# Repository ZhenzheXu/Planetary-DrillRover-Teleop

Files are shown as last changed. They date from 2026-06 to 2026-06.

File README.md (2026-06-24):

# Planetary-DrillRover-Teleop

An open-source, IPEx-inspired planetary rover analogue for sand-field mobility, drill-assisted soil interaction, multimodal teleoperation, and field-test data logging.

This repository supports the paper:

**OS-Rover: An Open-Source Planetary Rover for Resource Prospecting with Drill-Assisted Sampling and Multimodal Teleoperation**

The repository currently contains the STM32F407IGT6 firmware, Raspberry Pi software, SolidWorks mechanical source files, demonstration video, raw field-test logs, processed output plots, and paper figures used for the experimental analysis.

> This project is a terrestrial research prototype inspired by publicly available IPEx/RASSOR-style excavation rover concepts. It is not a flight-ready spacecraft and is not an official NASA project.

---

## 1. Project Overview

OS-Rover is a compact four-wheel skid-steer rover prototype developed as a reproducible terrestrial analogue platform for space robotics education, prototyping, sand-field testing, and human-in-the-loop control research.

The rover integrates:

* Four-wheel skid-steer mobility
* Large-diameter modular wheels with replaceable tread segments
* Drill-assisted soil loosening
* Rotating collection-disc mechanism
* Collection-module arm motion
* Arm-assisted recovery and pit-escape capability
* STM32F407IGT6-based real-time embedded control
* Raspberry Pi 5 high-level computing
* Vision-based gesture teleoperation
* Conventional radio control through FS-i6X / iA6B SBUS receiver
* Optional Bluetooth or terminal command interface
* Serial telemetry logging for field demonstrations

The prototype is intended for laboratory and sand-field experiments rather than vacuum, reduced-gravity, radiation, or flight environments.

---

## 2. Repository Structure

```text
Planetary-DrillRover-Teleop/
├── firmware/
│   └── stm32f407igt6_rover_controller/
│
├── software/
│   └── raspberry_pi/
│       ├── bluetooth_bridge/
│       ├── data_logger/
│       └── gesture_control/
│
├── mechanical/
│   └── solidworks_source/
│
├── data/
│   ├── raw_logs/
│   ├── processed_plots/
│   └── paper_figures/
│
├── media/
│   ├── os_rover_demo.mp4
│   └── os_rover_demo_thumbnail.png
│
└── README.md
```

---

## 3. Demonstration Video

The supplementary demonstration video is available below.

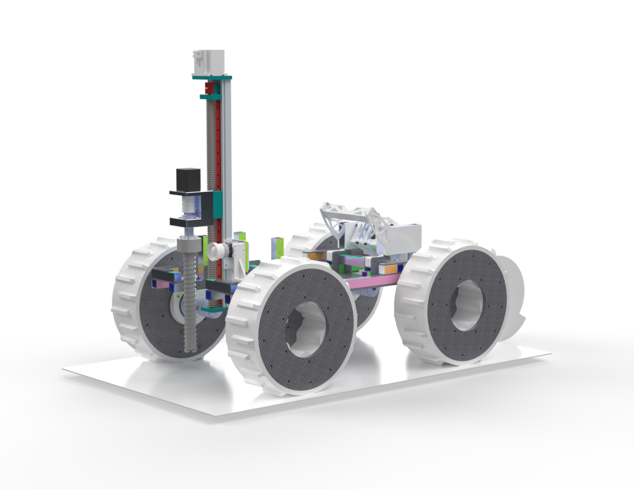
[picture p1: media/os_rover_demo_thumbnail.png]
OS-Rover demonstration video


The video presents 3D CAD model views, vision-based gesture control, collection-module arm motion, collection mechanism activation, four-wheel skid-steer mobility, drill-assisted soil interaction, pit-escape recovery, and telemetry feedback from the field tests.

---

## 4. Firmware

The STM32 firmware is located in:

```text
firmware/stm32f407igt6_rover_controller/
```

The firmware includes:

* Four-wheel chassis control
* CAN actuator control
* FS-i6X / iA6B SBUS receiver decoding
* Raspberry Pi serial command parsing
* Command arbitration between radio control and high-level commands
* Telemetry output for experiment logging

The project is configured for the STM32F407IGT6 controller and is organized as an STM32CubeMX / Keil MDK-ARM project.

---

## 5. Raspberry Pi Software

The Raspberry Pi software is located in:

```text
software/raspberry_pi/
```

The current software folders include:

* `gesture_control/`: vision-based gesture-control program
* `bluetooth_bridge/`: Bluetooth or terminal command bridge
* `data_logger/`: Python-based experiment logging scripts

The Raspberry Pi 5 is used for high-level command generation, gesture recognition, serial communication, and experiment data logging.

---

## 6. Mechanical Source Files

The mechanical source files are located in:

```text
mechanical/solidworks_source/
```

This folder contains the SolidWorks source files for the rover mechanical design, including the rover structure and functional modules.

The released mechanical files include source models related to:

* Rover chassis structure
* Wheel modules
* Drill mechanism
* Collection mechanism
* Collection-module arm structure

These files are provided as the current mechanical source release. Neutral CAD formats such as STEP files and printable STL files may be added in future updates.

---

## 7. Experimental Data and Result Plots

The experimental data are located in:

```text
data/
├── raw_logs/
├── processed_plots/
└── paper_figures/
```

* `raw_logs/` contains the original CSV telemetry logs recorded during field tests.
* `processed_plots/` contains output plots generated from the recorded log data.
* `paper_figures/` contains the final processed figures used in the paper.

The released data correspond to three field-test scenarios:

1. Flat-sand mobility and collection test
2. Slope-sand traversal test
3. Pit-escape recovery test

The logs include telemetry information such as wheel commands, control source, drill command, collection-disc command, collection-module arm state, and actuator feedback.

---

## 8. Example Result Figures

### Flat-Sand Test

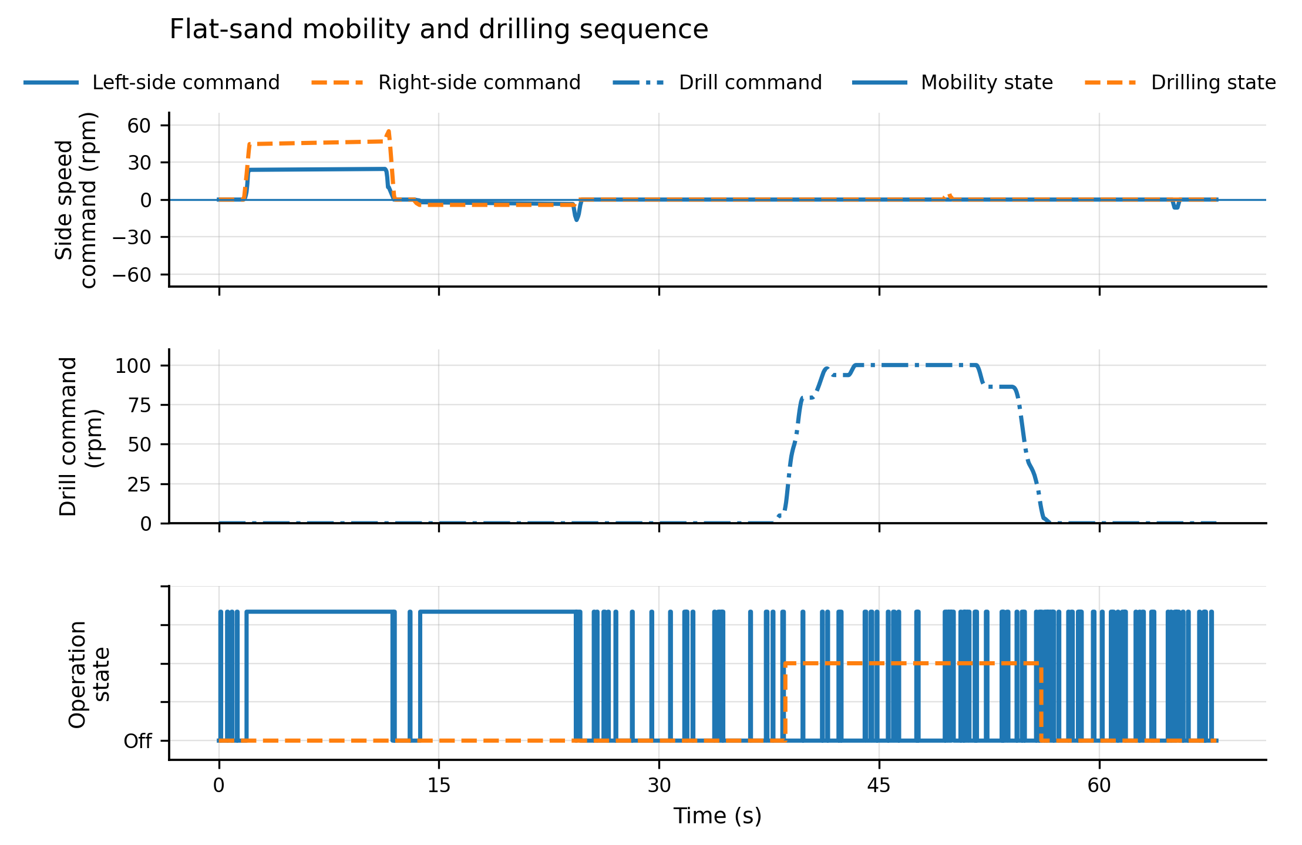
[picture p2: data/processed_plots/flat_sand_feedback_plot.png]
Flat-sand test result


### Slope-Traversal Test

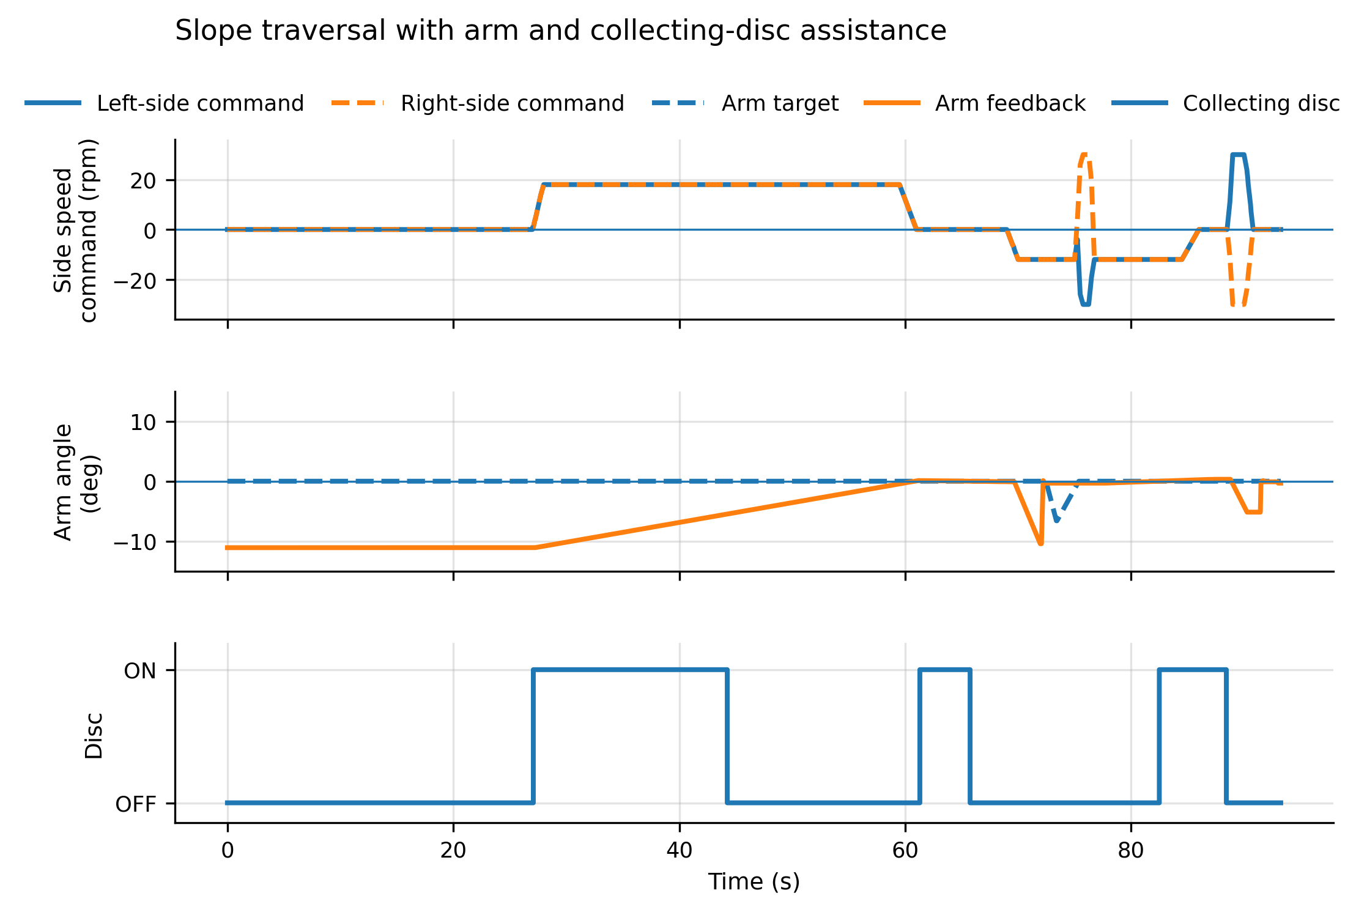
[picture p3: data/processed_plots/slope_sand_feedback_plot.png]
Slope-traversal test result


### Pit-Escape Test

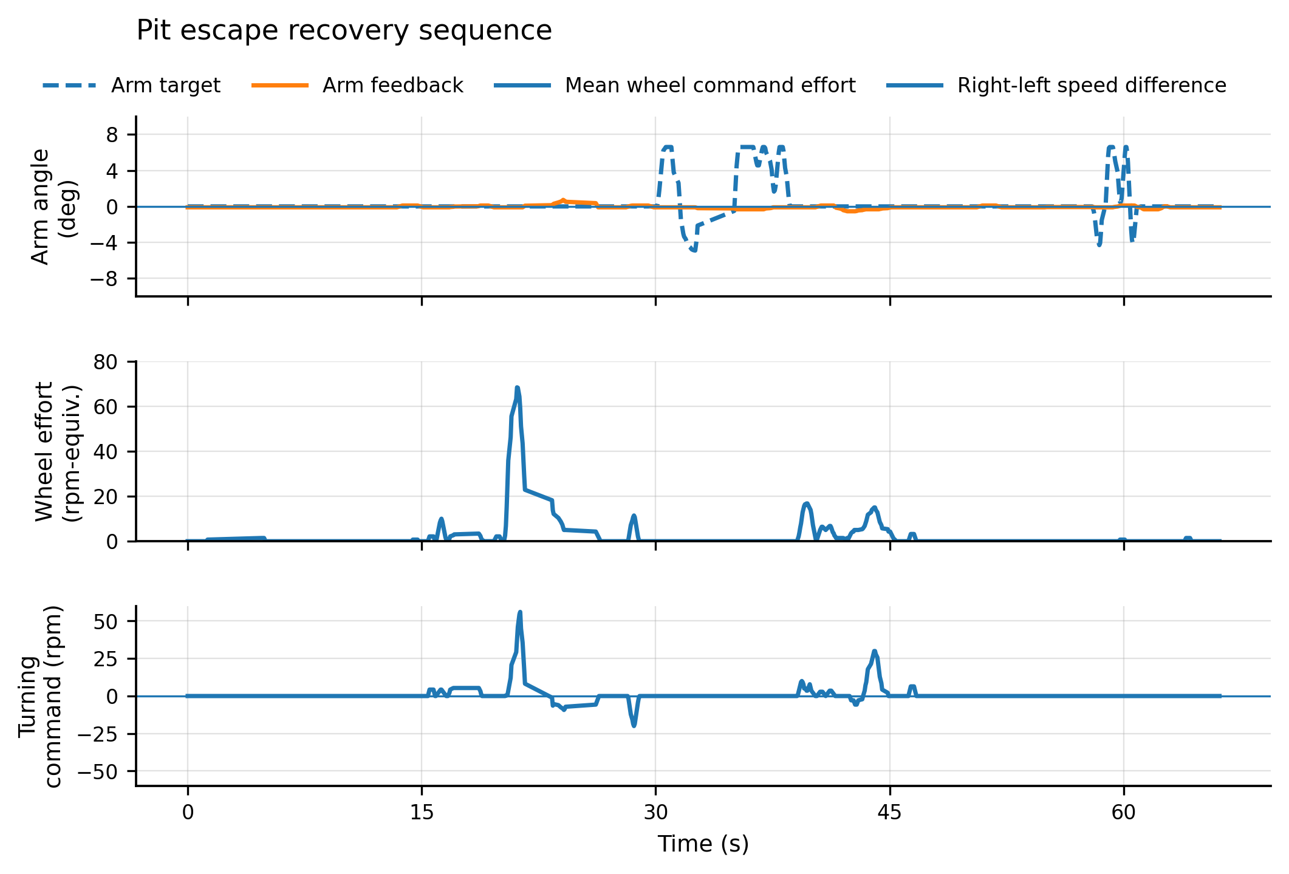
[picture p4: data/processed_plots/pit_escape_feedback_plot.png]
Pit-escape test result


### Paper Figure

Paper figure: three-scenario telemetry feedback

---

## 9. Field-Test Scenarios

### Flat-Sand Mobility and Collection Test

This scenario evaluates basic mobility, drill-assisted soil interaction, and collection-related actuation on flat sand.

### Slope-Sand Traversal Test

This scenario evaluates rover motion on inclined sandy terrain while recording the activity of the chassis and soil-working mechanisms.

### Pit-Escape Recovery Test

This scenario evaluates recovery behavior using coordinated chassis motion, drill actuation, collection-module arm motion, and collection mechanism activation.

---

## 10. Getting Started

### Clone the repository

```bash
git clone https://github.com/ZhenzheXu/Planetary-DrillRover-Teleop.git
cd Planetary-DrillRover-Teleop
```

### Open the STM32 firmware

Open the Keil project inside:

```text
firmware/stm32f407igt6_rover_controller/MDK-ARM/
```

or open the STM32CubeMX configuration file:

```text
firmware/stm32f407igt6_rover_controller/can.ioc
```

### Run Raspberry Pi scripts

Raspberry Pi scripts are organized under:

```text
software/raspberry_pi/
```

The gesture-control, Bluetooth bridge, and data-logging scripts are provided as the current high-level software release.

---

## 11. Current Release Status

This repository is under active development.

Current release contents:

* [x] STM32F407IGT6 rover-control firmware
* [x] Raspberry Pi software folders
* [x] SolidWorks mechanical source files
* [x] Demonstration video
* [x] Raw field-test logs
* [x] Processed output plots
* [x] Paper figures used for experimental analysis

Future updates may include additional wiring diagrams, neutral CAD exchange files, printable STL files, assembly notes, and extended operation documentation.

---

## 12. Citation

If you use this repository in academic work, please cite the related paper or this repository.

```bibtex
@misc{xu_planetary_drill_rover_2026,
  author       = {Xu, Zhenzhe},
  title        = {Planetary-DrillRover-Teleop: Open-source planetary drill rover teleoperation platform},
  year         = {2026},
  howpublished = {GitHub repository},
  url          = {https://github.com/ZhenzheXu/Planetary-DrillRover-Teleop}
}
```

---

## 13. License

A license file will be added before the final public release.

Recommended license structure:

* Firmware and software: MIT License or Apache-2.0
* Mechanical design files: CERN Open Hardware Licence or Creative Commons Attribution license

---

## 14. Safety Warning

This project is a research prototype intended for education, experimentation, and prototyping. It must be operated only by trained personnel in a controlled environment. Users are fully responsible for safe assembly, wiring, battery handling, and field operation. Do not operate the rover near people, unstable terrain, or hazardous conditions. The prototype is not intended for spaceflight, human-rated operation, or use in hazardous environments.

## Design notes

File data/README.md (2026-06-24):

# Experimental Data

This folder contains the experimental data and processed results used for the OS-Rover field demonstrations.

## Folder structure

- `raw_logs/` contains the original CSV telemetry logs recorded during the field tests.
- `processed_plots/` contains output plots generated from the recorded log data.
- `paper_figures/` contains the final processed figures used in the paper.

## Field-test scenarios

The released data correspond to three field-test scenarios:

1. Flat-sand mobility and collection test
2. Slope-sand traversal test
3. Pit-escape recovery test

The logs include telemetry information such as wheel commands, control source, drill command, collection-disc command, collection-module arm state, and actuator feedback. The processed plots summarize the task-level activity of the mobility system, drill module, arm mechanism, and collection mechanism during the experiments.

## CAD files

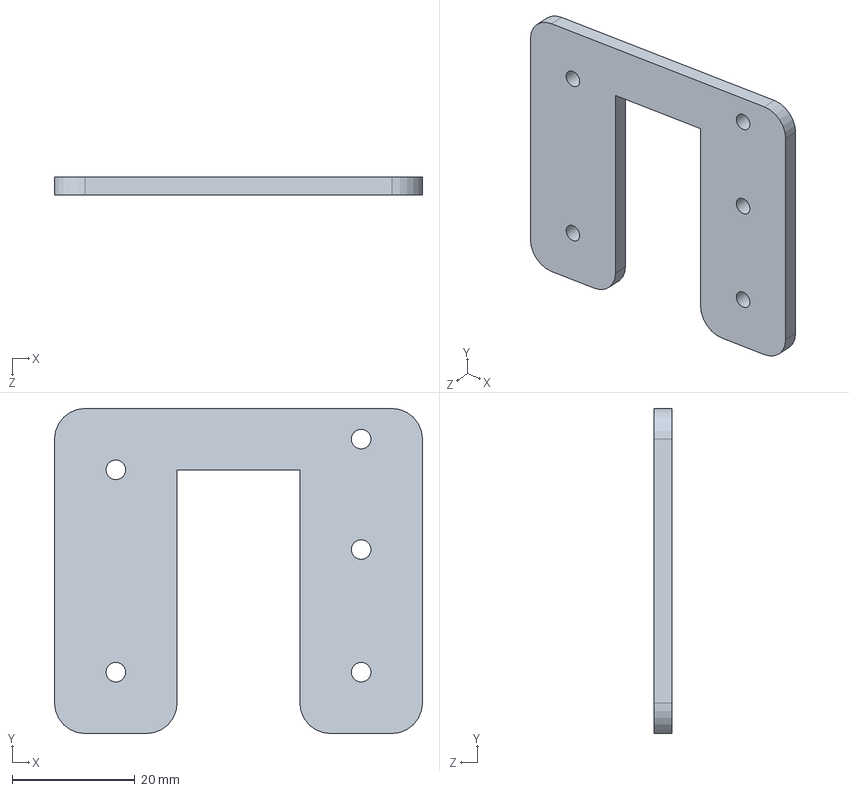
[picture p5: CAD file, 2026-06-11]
mechanical/solidworks_source/bucket_arm_vertical_column_reinforcement_plate.SLDPRT
60.0 x 53.0 x 3.00 mm

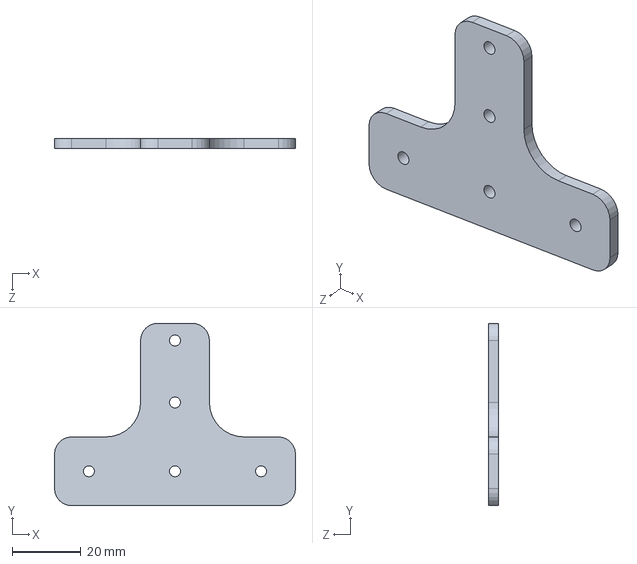
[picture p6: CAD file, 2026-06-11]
mechanical/solidworks_source/bucket_arm_vertical_aluminum_tube_2_mounting_plate.SLDPRT
70.0 x 53.0 x 3.00 mm

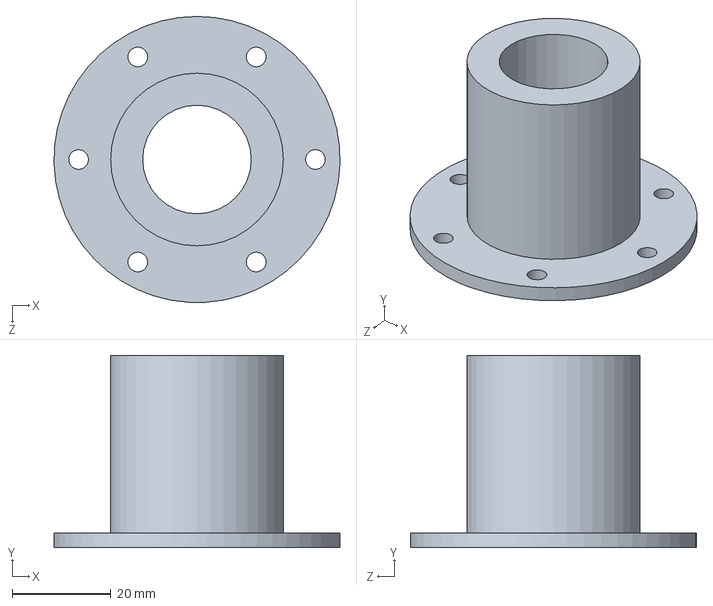
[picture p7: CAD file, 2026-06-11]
mechanical/solidworks_source/flange_plate.SLDPRT
58.0 x 39.0 x 58.0 mm

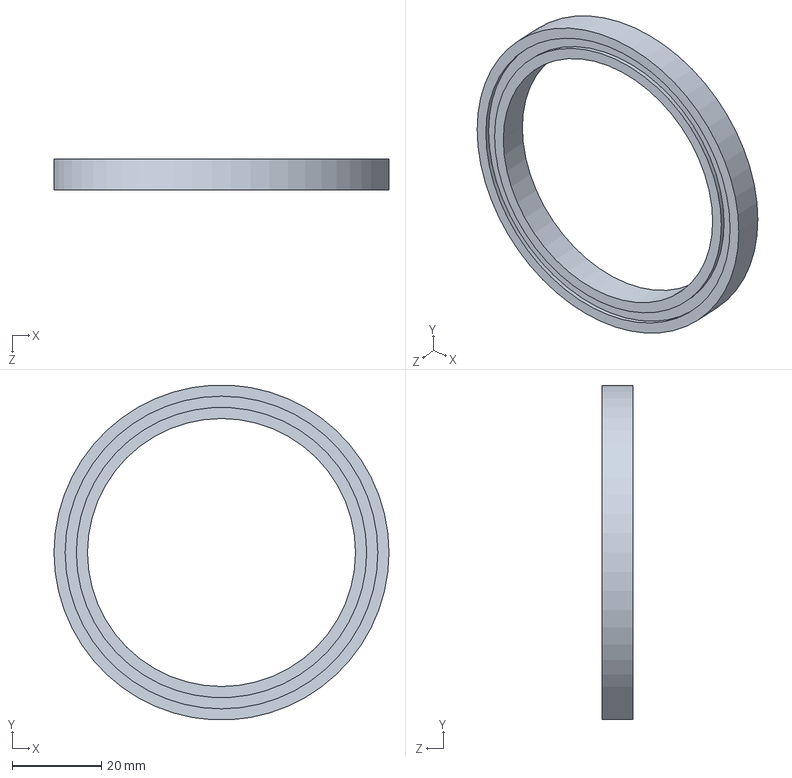
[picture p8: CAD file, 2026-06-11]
mechanical/solidworks_source/thin_section_deep_groove_ball_bearing_60x75x7.SLDPRT
75.0 x 74.9 x 7.00 mm

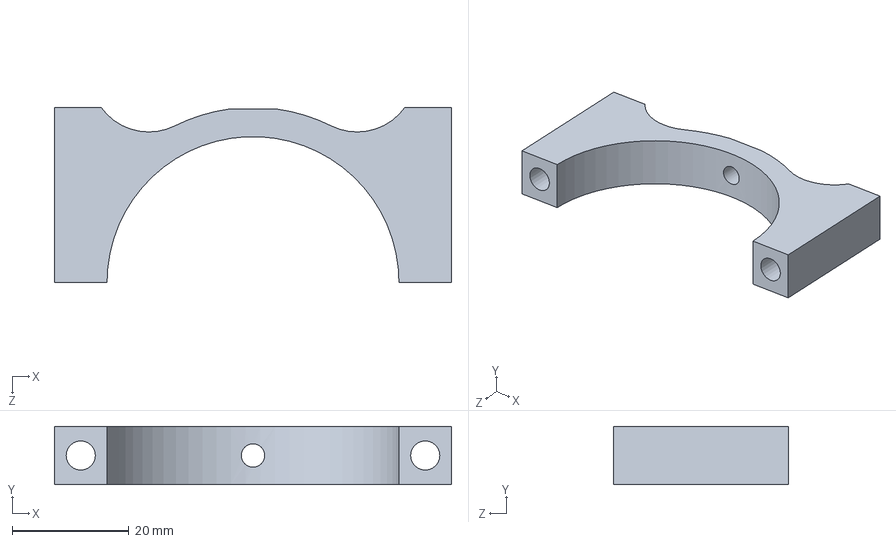
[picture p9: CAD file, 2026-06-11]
mechanical/solidworks_source/tube_clamp.SLDPRT
68.0 x 10.0 x 30.0 mm

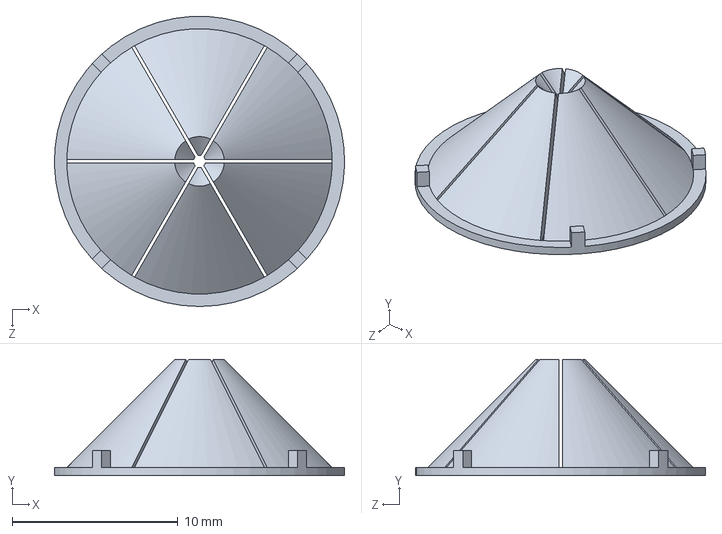
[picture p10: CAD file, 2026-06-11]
mechanical/solidworks_source/Sealing_Thin_Sheet.SLDPRT
17.5 x 7.01 x 17.5 mm

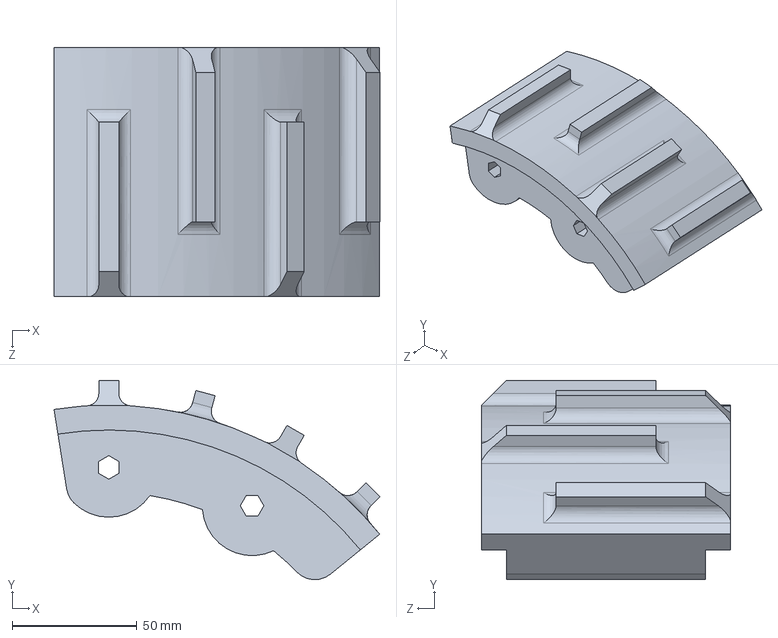
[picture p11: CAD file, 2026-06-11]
mechanical/solidworks_source/wheel_tread_staggered_rectangular_grouser_10mm_12x2_print_block.SLDPRT
130.9 x 80.0 x 100.0 mm

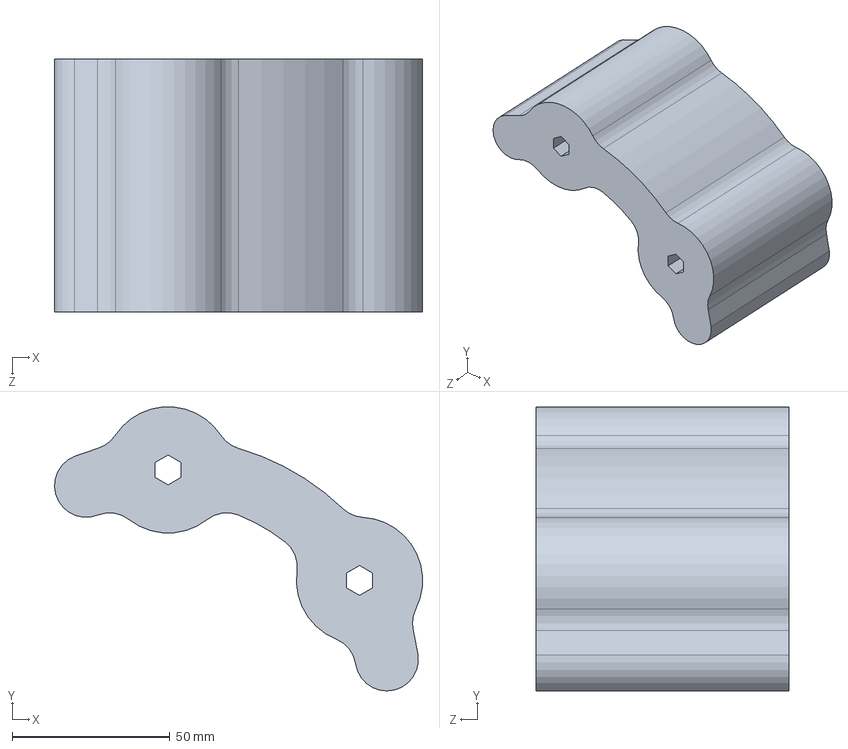
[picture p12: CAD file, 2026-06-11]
mechanical/solidworks_source/wheel_module_inner_spacer.SLDPRT
116.5 x 89.9 x 80.0 mm

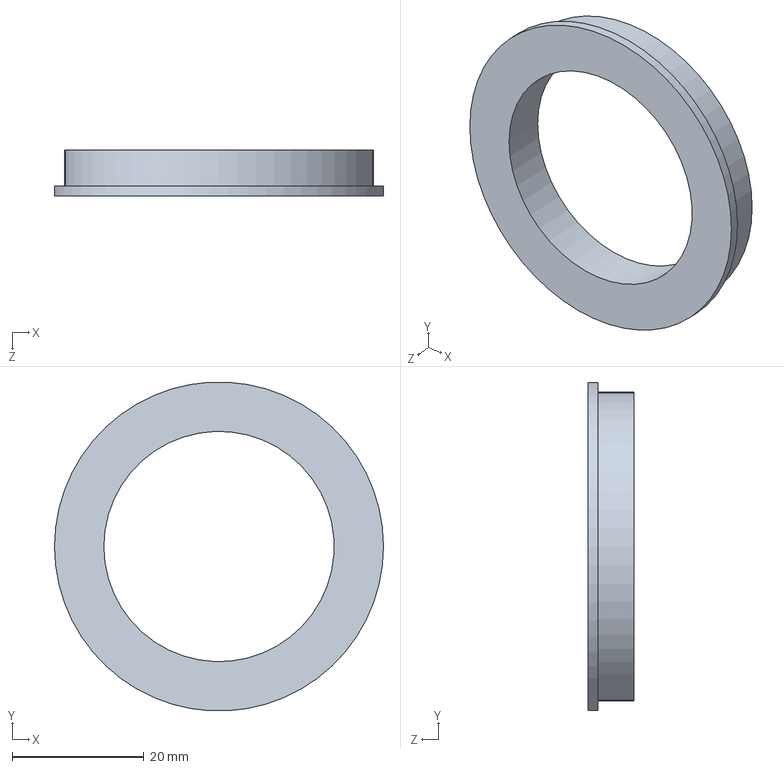
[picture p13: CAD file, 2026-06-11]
mechanical/solidworks_source/Flanged_Bearing_35-55-10.SLDPRT
50.0 x 49.9 x 7.00 mm

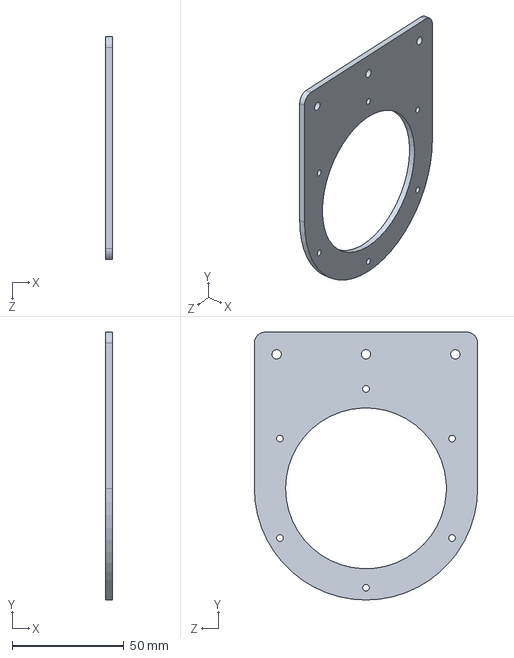
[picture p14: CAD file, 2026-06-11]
mechanical/solidworks_source/bearing_inner_clamping_plate_60x78.SLDPRT
3.00 x 120.0 x 100.0 mm

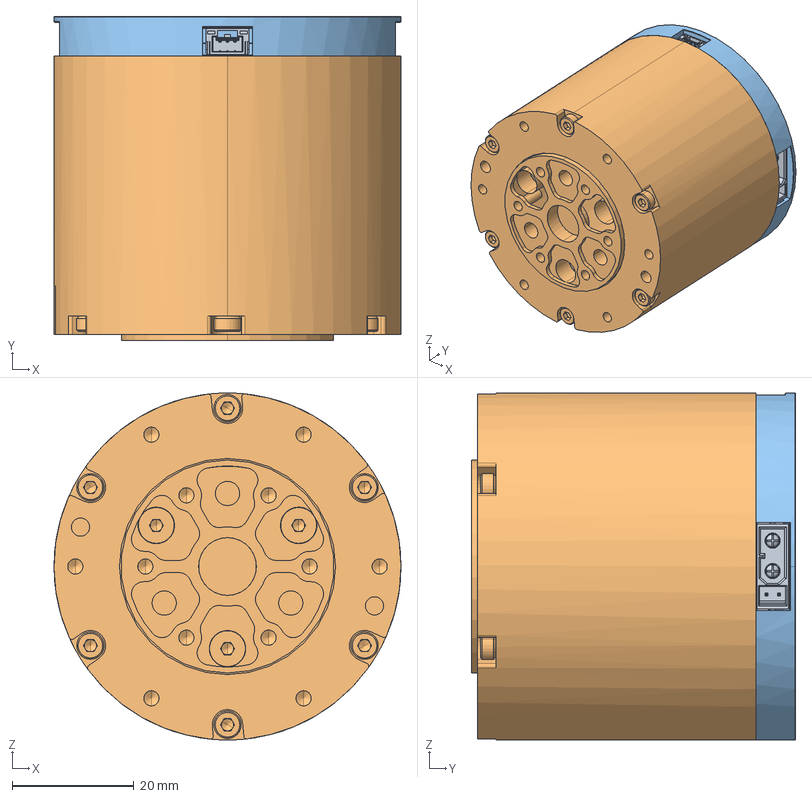
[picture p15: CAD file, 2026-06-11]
mechanical/solidworks_source/dm_4340__3d20240822_1(2)(1).stp
57.0 x 53.3 x 57.0 mm
DM_4340_3D_1_1_1_1_4
4310__VER_B0001_1_1_1_1_4
G43_V1_1_3-230824_4

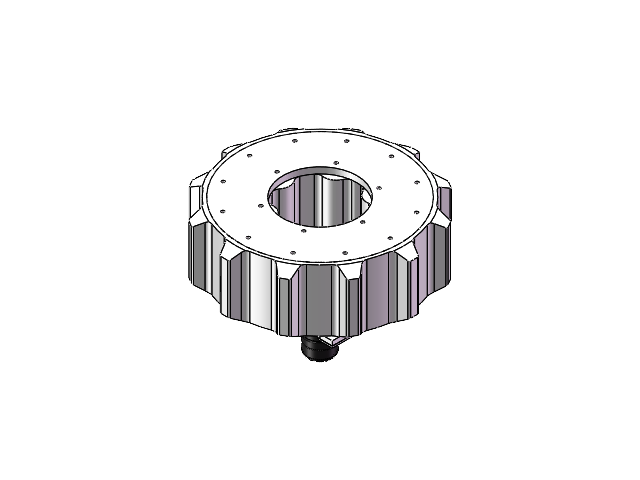
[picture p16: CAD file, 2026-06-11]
mechanical/solidworks_source/m3508_wheel_module.SLDASM
M3508直流无刷减速电机
3508法兰盘联轴器-hhr
淘宝-坚威旗舰店-杯头内六角螺丝M1,4M2M3M4M5M6 x 13
淘宝-坚威旗舰店-防松自紧螺母 x 6
铜柱5-80-hhr
3508法兰盘转接件-hhr
60-78-10薄壁深沟球轴承-hhr
3508安装板-hhr
60-78轴承内压板-hhr
60-78轴承垫块-hhr
60-78轴承外压板-hhr
60-78轴承外侧内圈压板-hhr
65-78轴承内侧外垫块-hhr
轮侧板-hhr
轮组内垫块-hhr x 3
轮组安装垫块-hhr
外轮板-hhr

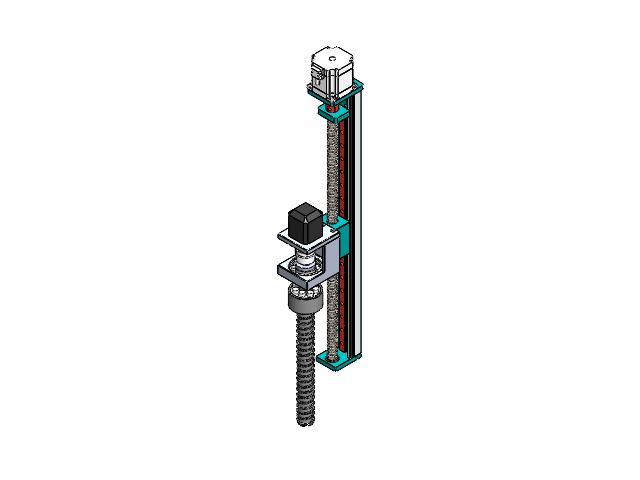
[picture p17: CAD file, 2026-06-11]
mechanical/solidworks_source/drilling_system_sample_assembly.SLDASM
传导轴
钻取平台
钻取平台连接板
42电机示意模型
联轴器示意模型
胀紧套ZJ2-18×47示意模型
螺纹钻管
防漏薄片
取芯钻头
______304mm.STEP
________.STEP
______.STEP
zhoucheng.STEP x 2
________-0.STEP
______-1.STEP
______-2.STEP
____.STEP
________-3.STEP
lianzhouqi.STEP
57______.STEP
57____.STEP

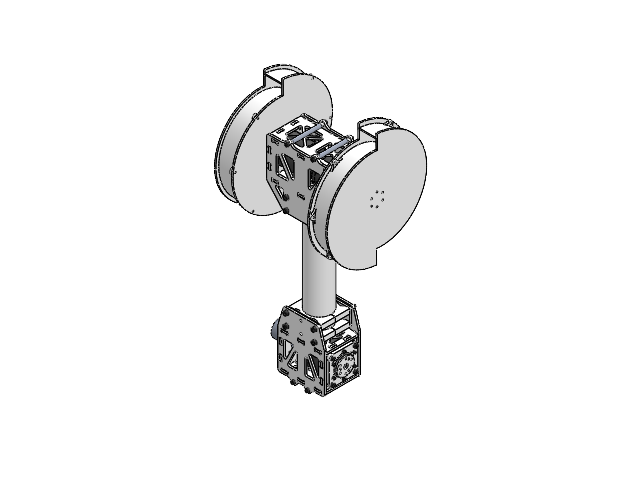
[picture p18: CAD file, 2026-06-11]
mechanical/solidworks_source/lever_arm_assembly.SLDASM
圆柱长臂
管夹 x 8
DM_4340_3D_1_1_1_1_4_1.stp x 3
4310__VER_B0001_1_1_1_1_4_1.stp x 3
G43_V1_1_3-230824_4_1.stp x 3
管夹固定板 x 4
t型连接板 x 2
t型连接支撑板 x 2
旋转轴 x 3
电机固定板 x 3
深沟球35-44-5 x 3
轴承固定 x 3
内六角圆柱头螺钉 M3x12 x 18
圆柱销 Φ4x25 x 6
内六角圆柱头螺钉 M4x15 x 4
内六角圆柱头螺钉 M4x12 x 14
内六角圆柱头螺钉 M3x22 x 12
内六角圆柱头螺钉 M5x85 x 8
内六角圆柱头螺钉 M4x16 x 4
轴系垫高打印件
螺旋挡板1
侧板2 x 2
固定板
法兰盘
固定垫片
t型连接板2 x 2
t型连接支撑板2 x 2
淘宝-坚威旗舰店-防松自紧螺母 x 2
60mm铝柱 x 4
尼龙套柱 x 8
螺旋挡板(左侧)

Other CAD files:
mechanical/solidworks_source/angular_contact_ball_bearing_7205c_gbt_292_2023.SLDASM
mechanical/solidworks_source/left_bucket_drum_assembly.SLDASM
mechanical/solidworks_source/bucket_drum_assembly.SLDASM
mechanical/solidworks_source/tube_clamp_assembly.SLDASM
mechanical/solidworks_source/Aluminum_Block_8_8_25.SLDPRT
mechanical/solidworks_source/Bucket_Arm_Stopper.SLDPRT
mechanical/solidworks_source/Bucket_Arm_Upright_Reinforcement_Clamp_Block.SLDPRT
mechanical/solidworks_source/Camera_Mounting_Bracket.SLDPRT
mechanical/solidworks_source/End_Cover_Spacer.SLDPRT
mechanical/solidworks_source/Flange_End_Cover.SLDPRT
mechanical/solidworks_source/Flanged_Bearing_Spacer_3D_Printed_Part.SLDPRT
mechanical/solidworks_source/Flanged_Bearing_Washer.SLDPRT
mechanical/solidworks_source/Long_Cylindrical_Arm.SLDPRT
mechanical/solidworks_source/MV-CU013-A0UMUC.SLDPRT
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

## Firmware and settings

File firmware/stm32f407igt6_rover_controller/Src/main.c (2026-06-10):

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

/* Includes ------------------------------------------------------------------*/
#include "main.h"
#include "can.h"
#include "dma.h"
#include "usart.h"
#include "gpio.h"

/* USER CODE BEGIN Includes */
#include "bsp_can.h"
#include "CAN_receive.h"
#include "i6x_receive.h"
#include "i6x.h"
#include <string.h>
#include <stdlib.h>
#include <stdio.h>
/* USER CODE END Includes */

/* USER CODE BEGIN PTD */

typedef struct
{
    float kp;
    float ki;
    float kd;

    float err;
    float last_err;
    float integral;

    float max_out;
    float max_integral;
} motor_pid_t;

typedef enum
{
    CONTROL_SOURCE_REMOTE = 0,
    CONTROL_SOURCE_VISION = 1
} control_source_t;

typedef struct
{
    uint8_t online;
    uint8_t err;
    uint8_t id;

    uint16_t pos_raw;
    uint16_t vel_raw;
    uint16_t torque_raw;

    float pos_rad;
    float vel_rad_s;
    float torque_nm;

    uint8_t t_mos;
    uint8_t t_rotor;

    uint32_t last_update_tick;
    uint32_t rx_count;
} dm4340_feedback_t;

/* USER CODE END PTD */

/* USER CODE BEGIN PD */

/* ========================= M3508 Chassis Definition ========================= */

#define LF_DIR   1
#define RF_DIR  -1
#define LR_DIR   1
#define RR_DIR  -1

#define RC_FORWARD_CH       1
#define RC_TURN_CH          0

#define RC_FORWARD_SIGN     1.0f
#define RC_TURN_SIGN        1.0f

#define RC_CH_MAX_VALUE     660.0f
#define RC_DEADBAND         35

#define MAX_FORWARD_RPM     220.0f
#define MAX_TURN_RPM        180.0f

#define PID_MAX_OUT         10000.0f
#define PID_MAX_INTEGRAL    30000.0f

#define CHASSIS_CONTROL_PERIOD_MS   2U

/* ========================= Raspberry Pi Vision UART Definition ========================= */

#define VISION_DEFAULT_SPEED_RPM       120.0f
#define VISION_DEFAULT_TURN_RPM        120.0f

#define VISION_UART_LINE_MAX_LEN       64U

/*
 * Telemetry output uses a second UART to avoid conflict with Raspberry Pi
 * gesture-control serial port.
 * Keep USART1 for gesture commands. Use USART6 TX -> second USB-TTL RX for feedback.
 * If your CubeMX enables another UART such as USART2, change huart6 to huart2.
 */
#define TELEMETRY_UART_HANDLE          huart6

/*
 * Arbitration rule required by user:
 *   1) If Raspberry Pi sends a valid hand gesture command, vision has priority.
 *   2) If the remote controller sends an active command, remote control can take back control.
 *   3) If the remote controller has no active command for 10 seconds, return to vision control.
 *
 * Note:
 *   STOP_ALL from Raspberry Pi is treated as a stop state, but it does not take control
 *   away from an actively used remote controller. This prevents NO_HAND -> STOP_ALL
 *   from blocking manual remote control.
 */
#define RC_IDLE_TO_VISION_MS           10000U
#define VISION_GESTURE_HOLD_MS         1200U
#define VISION_COMMAND_TIMEOUT_MS      1200U

/* ========================= DM4340 CAN2 Definition ========================= */

#define DM_LEFT_UP_ID              0x01
#define DM_LEFT_DOWN_ID            0x02
#define DM_RIGHT_ROTATE_ID         0x03

/*
 * i6X switch mapping:
 * s[0] = SwA
 * s[1] = SwB
 * s[2] = SwC
 * s[3] = SwD
 */
#define DM_DISC_SWITCH_INDEX       0
#define DM_RIGHT_SWITCH_INDEX      1

#define DM_DISC_SPEED_RAD_S        0.5f
#define DM_LEFT_UP_DIR             1.0f
#define DM_LEFT_DOWN_DIR          -1.0f

#define RIGHT_POS_0_RAD            0.0f
#define RIGHT_POS_90_RAD           1.5707963f

/*
 * Manual self-rescue control for CAN2 DM4340 ID3.
 *
 * Original SwB logic is kept unchanged:
 *   SwB down -> 90 deg
 *   SwB up   -> 0 deg
 *
 * New left-stick horizontal incremental control:
 *   left  -> negative rotation
 *   right -> positive rotation
 *   center -> stop at and hold the last commanded position
 *
 * This is NOT a one-shot limit-position command. The target position is
 * integrated gradually according to stick deflection and is clamped to
 * [-45 deg, +180 deg] to protect the cable.
 *
 * Current project convention:
 *   ch[0]/ch[1] are used for chassis drive.
 *   ch[3] is used here as the left-stick horizontal channel.
 *
 * If the physical stick direction is opposite after testing, change
 * DM_RIGHT_MANUAL_SIGN from 1.0f to -1.0f.
 */
#define DM_RIGHT_MANUAL_CH             3U
#define DM_RIGHT_MANUAL_DEADBAND       120
#define DM_RIGHT_MANUAL_SIGN           1.0f
#define DM_RIGHT_MANUAL_STICK_MAX      660.0f
#define RIGHT_POS_MANUAL_MIN_RAD      -0.7853982f   /* -45 deg */
#define RIGHT_POS_MANUAL_MAX_RAD       3.1415927f   /* +180 deg */

#define RIGHT_POS_SPEED_RAD_S      0.25f
/*
 * Manual control strategy:
 * While the left stick is held left/right, send a stable far target
 * (-45 deg or +180 deg) and let DM4340 move smoothly with the same
 * velocity limit as SwB.  Meanwhile, the code estimates the current
 * arm angle according to RIGHT_POS_SPEED_RAD_S.  When the stick returns
 * to center, the estimated current angle is immediately sent as the new
 * target, so the arm stops and holds its current position.
 */
#define DM_SEND_PERIOD_MS          5U

/*
 * DM4340 feedback decoding and telemetry output.
 *
 * DM4340 feedback frame format from the manual:
 *   STD ID = Master ID, default 0
 *   D0 = ID | (ERR << 4)
 *   D1-D2 = POS, 16-bit
 *   D3-D4 = VEL, 12-bit
 *   D4-D5 = T,   12-bit
 *   D6 = MOS temperature
 *   D7 = rotor temperature
 *
 * PMAX/VMAX/TMAX must match the values configured in Damiao Assistant.
 * These default values are used for first-stage logging. If the angle scale
 * is obviously wrong, read PMAX/VMAX/TMAX from the assistant and update here.
 */
#define DM_FEEDBACK_P_MAX_RAD       12.5f
#define DM_FEEDBACK_V_MAX_RAD_S     45.0f
#define DM_FEEDBACK_T_MAX_NM        40.0f
#define DM_FEEDBACK_OFFLINE_MS      500U

#define TELEMETRY_SEND_PERIOD_MS    50U
#define TELEMETRY_UART_TIMEOUT_MS   5U
#define TELEMETRY_LINE_MAX_LEN      512U

#define DM_REG_CTRL_MODE           0x0A

#define DM_MODE_POS_VEL            2
#define DM_MODE_VELOCITY           3

/* ========================= ZDT57 CAN2 Definition ========================= */

/*
 * ZDT57 open-loop CAN control on CAN2.
 *
 * 57 driver board settings:
 *   FWType    = FW_X
 *   CtrlMode  = CR_OPEN
 *   P_Serial  = CAN1_MAP / CAN
 *   ID_Addr   = 4
 *   CAN_Baud  = same as CAN2 / DM4340
 *   Checksum  = 0x6B
 *   En        = Hold
 *   Ma        = 2000mA first
 */
#define ZDT57_ID                  4U

/*
 * Required by user:
 *   SwC up     -> stop
 *   SwC middle -> reverse
 *   SwC down   -> forward
 *
 * In current i6x.c:
 *   rc->s[2] is already mapped to -1 / 0 / 1.
 */
#define ZDT57_SWITCH_INDEX        2U

/*
 * X firmware speed command uses 0.1 rpm unit.
 * 600 = 60.0 rpm.
 */
#define ZDT57_SPEED_RPM_X10       600U
#define ZDT57_ACC_RPM_S           300U

/*
 * If actual mechanical direction is opposite, swap these two values.
 */
#define ZDT57_DIR_FORWARD         0U
#define ZDT57_DIR_REVERSE         1U

#define ZDT57_SEND_PERIOD_MS      50U

/* ========================= ZDT42 CAN2 Definition ========================= */

/*
 * ZDT42 closed-loop CAN control on CAN2.
 *
 * 42 driver board settings:
 *   FWType    = FW_X
 *   CtrlMode  = CR_VFOC
 *   P_Serial  = CAN1_MAP / CAN
 *   ID_Addr   = 5
 *   CAN_Baud  = same as CAN2 / DM4340
 *   Checksum  = 0x6B
 *   En        = Hold
 *   Response  = None or Receive
 *
 * Required by user:
 *   SwD up   -> OFF / stop
 *   SwD down -> ON / run
 *   VRB clockwise -> speed increases
 */
#define ZDT42_ID                  5U
#define ZDT42_SWITCH_INDEX        3U

/*
 * In current i6x.c:
 *   ch[0]~ch[5] are mapped to -660 ~ 660.
 *
 * Usually:
 *   VRA -> ch[4]
 *   VRB -> ch[5]
 */
#define ZDT42_VRB_CH              5U

/*
 * Unit: 0.1 rpm.
 * 1000 = 100.0 rpm.
 * Increase this later if the drill needs higher speed.
 */
#define ZDT42_MIN_SPEED_RPM_X10   0U
#define ZDT42_MAX_SPEED_RPM_X10   1000U

#define ZDT42_ACC_RPM_S           200U

/*
 * Direction when SwD is down.
 * If the drill rotation direction is wrong, change 0U to 1U.
 */
#define ZDT42_DIR_RUN             0U

#define ZDT42_SEND_PERIOD_MS      50U

/* USER CODE END PD */


/* USER CODE BEGIN PV */

static motor_pid_t pid_lf = {12.0f, 0.08f, 0.0f, 0.0f, 0.0f, 0.0f, PID_MAX_OUT, PID_MAX_INTEGRAL};
static motor_pid_t pid_rf = {12.0f, 0.08f, 0.0f, 0.0f, 0.0f, 0.0f, PID_MAX_OUT, PID_MAX_INTEGRAL};
static motor_pid_t pid_lr = {12.0f, 0.08f, 0.0f, 0.0f, 0.0f, 0.0f, PID_MAX_OUT, PID_MAX_INTEGRAL};
static motor_pid_t pid_rr = {12.0f, 0.08f, 0.0f, 0.0f, 0.0f, 0.0f, PID_MAX_OUT, PID_MAX_INTEGRAL};

static CAN_TxHeaderTypeDef dm_tx_header;
static uint32_t dm_tx_mailbox;

static CAN_TxHeaderTypeDef zdt_tx_header;
static uint32_t zdt_tx_mailbox;

/* Raspberry Pi vision UART receive */
static uint8_t vision_uart_rx_byte = 0;
static char vision_uart_line[VISION_UART_LINE_MAX_LEN];
static uint8_t vision_uart_line_len = 0;

static volatile uint8_t vision_mode_active = 0;
static volatile uint32_t vision_last_cmd_tick = 0U;
static volatile uint32_t vision_last_gesture_tick = 0U;

static volatile float vision_left_rpm = 0.0f;
static volatile float vision_right_rpm = 0.0f;

/*
 * In this project, Python DRILL_ON / DRILL_OFF are intentionally used
 * to control the collecting disc: CAN2 DM4340 ID1 and ID2.
 * The real drill motor ZDT42 is always controlled by remote controller SwD + VRB only.
 */
static volatile uint8_t vision_disc_enabled = 0;
static volatile float vision_right_target_pos = RIGHT_POS_0_RAD;

static volatile control_source_t current_control_source = CONTROL_SOURCE_REMOTE;
static uint32_t rc_last_active_tick = 0U;

/*
 * ID3 manual self-rescue state.
 * dm_right_manual_hold_active keeps the arm holding the last manual target
 * after the left stick returns to center.
 */
static float dm_right_last_target_pos = RIGHT_POS_0_RAD;
static float dm_right_manual_target_pos = RIGHT_POS_0_RAD;
static uint8_t dm_right_manual_hold_active = 0U;
static uint32_t dm_right_manual_last_tick = 0U;

/* DM4340 ID3 feedback for Raspberry Pi logging */
static volatile dm4340_feedback_t dm3_feedback;

/* Integrated rover telemetry state for paper experiments */
static volatile float log_lf_target_rpm = 0.0f;
static volatile float log_rf_target_rpm = 0.0f;
static volatile float log_lr_target_rpm = 0.0f;
static volatile float log_rr_target_rpm = 0.0f;

static volatile uint8_t log_disc_cmd_enabled = 0U;
static volatile uint8_t log_zdt42_cmd_enabled = 0U;
static volatile uint16_t log_zdt42_cmd_speed_x10 = 0U;

/* USER CODE END PV */

void SystemClock_Config(void);
/* USER CODE BEGIN PFP */

/* Chassis functions */
static float limit_float(float input, float min, float max);
static void pid_clear(motor_pid_t *pid);
static int16_t pid_calc(motor_pid_t *pid, float target, float feedback);
static int16_t rc_deadband(int16_t value);
static float rc_to_rpm(int16_t value, float max_rpm);
static void chassis_stop(void);
static void chassis_speed_set(float lf_rpm, float rf_rpm, float lr_rpm, float rr_rpm);
static void chassis_remote_control(void);

/* Raspberry Pi vision UART functions */
static void Vision_UART_Start(void);
static void Vision_UART_Parse_Byte(uint8_t byte);
static void Vision_UART_Execute_Line(const char *line);
static float Vision_Parse_Speed(const char *str, float default_speed, float max_speed);
static void Vision_Mark_Valid_Gesture(void);
static uint8_t Vision_Gesture_Is_Recent(void);
static uint8_t Vision_Command_Is_Timed_Out(void);
static void Vision_Set_Stop_All(void);
static void Vision_Set_Drive(float left_rpm, float right_rpm);
static uint8_t Remote_Command_Is_Active(void);
static void Control_Source_Update(void);
static void chassis_vision_control(void);
static void DM_Vision_Control(void);

/* DM4340 functions */
static void DM_CAN2_Start_If_Needed(void);
static uint8_t DM_CAN2_Send(uint32_t std_id, uint8_t *data, uint8_t len);

static void DM_Write_Uint32_Register(uint16_t can_id, uint8_t reg, uint32_t value);
static void DM_Set_Control_Mode(uint16_t can_id, uint32_t mode);

static void DM_Velocity_Clear_Error(uint16_t can_id);
static void DM_Velocity_Enable(uint16_t can_id);
static void DM_Velocity_Disable(uint16_t can_id);
static void DM_Set_Velocity(uint16_t can_id, float vel_rad_s);

static void DM_PosVel_Clear_Error(uint16_t can_id);
static void DM_PosVel_Enable(uint16_t can_id);
static void DM_PosVel_Disable(uint16_t can_id);
static void DM_PosVel_Set_Zero(uint16_t can_id);
static void DM_Set_Position_Velocity(uint16_t can_id, float pos_rad, float vel_rad_s);

static void DM_Init_Collecting_Disc(uint16_t can_id);
static void DM_Init_Right_Rotate_Motor(uint16_t can_id);
static void DM_Stop_All(void);

static void DM_CAN2_Feedback_Filter_Init(void);
static void DM_CAN2_Feedback_Start(void);
static float DM_Uint_To_Float(uint32_t x_int, float x_min, float x_max, uint8_t bits);
static void DM_Parse_Feedback_Frame(CAN_RxHeaderTypeDef *rx_header, uint8_t *rx_data);

static float DM_Clamp_Right_Manual_Target(float target_pos);
static int16_t DM_Get_Right_Manual_Stick(i6x_ctrl_t *rc);
static uint8_t DM_Right_Manual_Is_Active(i6x_ctrl_t *rc);
static void DM_Right_Send_Position(float target_pos, float speed_rad_s);
static void DM_Remote_Control(void);

/* ZDT CAN2 functions */
static uint8_t ZDT_CAN2_Send_Ext(uint8_t addr, uint8_t packet, uint8_t *data, uint8_t len);
static void ZDT_CAN2_Send_X_Speed(uint8_t addr, uint8_t dir, uint16_t acc_rpm_s, uint16_t speed_rpm_x10);

static void ZDT57_Stop(void);
static void ZDT57_Remote_Control(void);

static void ZDT42_Stop(void);
static uint16_t ZDT42_Get_VRB_Speed_X10(i6x_ctrl_t *rc);
static void ZDT42_Remote_Control(void);

/* Raspberry Pi telemetry */
static void Telemetry_Send_DM3(void);

/* USER CODE END PFP */

/* USER CODE BEGIN 0 */

/* ========================= Chassis Control ========================= */

static float limit_float(float input, float min, float max)
{
    if (input > max)
    {
        return max;
    }
    else if (input < min)
    {
        return min;
    }
    else
    {
        return input;
    }
}

static void pid_clear(motor_pid_t *pid)
{
    pid->err = 0.0f;
    pid->last_err = 0.0f;
    pid->integral = 0.0f;
}

static int16_t pid_calc(motor_pid_t *pid, float target, float feedback)
{
    float out;

    pid->err = target - feedback;

    pid->integral += pid->err;
    pid->integral = limit_float(pid->integral,
                                -pid->max_integral,
                                pid->max_integral);

    out = pid->kp * pid->err
        + pid->ki * pid->integral
        + pid->kd * (pid->err - pid->last_err);

    pid->last_err = pid->err;

    out = limit_float(out, -pid->max_out, pid->max_out);

    return (int16_t)out;
}

static int16_t rc_deadband(int16_t value)
{
    if (value > -RC_DEADBAND && value < RC_DEADBAND)
    {
        return 0;
    }

    return value;
}

static float rc_to_rpm(int16_t value, float max_rpm)
{
    float rpm;

    value = rc_deadband(value);

    rpm = ((float)value / RC_CH_MAX_VALUE) * max_rpm;
    rpm = limit_float(rpm, -max_rpm, max_rpm);

    return rpm;
}

static void chassis_stop(void)
{
    pid_clear(&pid_lf);
    pid_clear(&pid_rf);
    pid_clear(&pid_lr);
    pid_clear(&pid_rr);

    log_lf_target_rpm = 0.0f;
    log_rf_target_rpm = 0.0f;
    log_lr_target_rpm = 0.0f;
    log_rr_target_rpm = 0.0f;

    CAN_cmd_chassis(0, 0, 0, 0);
}

static void chassis_speed_set(float lf_rpm, float rf_rpm, float lr_rpm, float rr_rpm)
{
    const motor_measure_t *lf_motor;
    const motor_measure_t *rf_motor;
    const motor_measure_t *lr_motor;
    const motor_measure_t *rr_motor;

    float lf_target_raw;
    float rf_target_raw;
    float lr_target_raw;
    float rr_target_raw;

    int16_t lf_current;
    int16_t rf_current;
    int16_t lr_current;
    int16_t rr_current;

    log_lf_target_rpm = lf_rpm;
    log_rf_target_rpm = rf_rpm;
    log_lr_target_rpm = lr_rpm;
    log_rr_target_rpm = rr_rpm;

    lf_motor = get_chassis_motor_measure_point(0);
    rf_motor = get_chassis_motor_measure_point(1);
    lr_motor = get_chassis_motor_measure_point(2);
    rr_motor = get_chassis_motor_measure_point(3);

    lf_target_raw = LF_DIR * lf_rpm;
    rf_target_raw = RF_DIR * rf_rpm;
    lr_target_raw = LR_DIR * lr_rpm;
    rr_target_raw = RR_DIR * rr_rpm;

    lf_current = pid_calc(&pid_lf, lf_target_raw, (float)lf_motor->speed_rpm);
    rf_current = pid_calc(&pid_rf, rf_target_raw, (float)rf_motor->speed_rpm);
    lr_current = pid_calc(&pid_lr, lr_target_raw, (float)lr_motor->speed_rpm);
    rr_current = pid_calc(&pid_rr, rr_target_raw, (float)rr_motor->speed_rpm);

    CAN_cmd_chassis(lf_current, rf_current, lr_current, rr_current);
}

static void chassis_remote_control(void)
{
    i6x_ctrl_t *rc;
    float forward_rpm;
    float turn_rpm;

    float left_rpm;
    float right_rpm;

    rc = get_i6x_point();

    if (rc->failsafe)
    {
        chassis_stop();
        return;
    }

    forward_rpm = RC_FORWARD_SIGN * rc_to_rpm(rc->ch[RC_FORWARD_CH], MAX_FORWARD_RPM);
    turn_rpm    = RC_TURN_SIGN    * rc_to_rpm(rc->ch[RC_TURN_CH],    MAX_TURN_RPM);

    left_rpm  = forward_rpm + turn_rpm;
    right_rpm = forward_rpm - turn_rpm;

    left_rpm  = limit_float(left_rpm,  -MAX_FORWARD_RPM, MAX_FORWARD_RPM);
    right_rpm = limit_float(right_rpm, -MAX_FORWARD_RPM, MAX_FORWARD_RPM);

    chassis_speed_set(left_rpm, right_rpm, left_rpm, right_rpm);
}

/* ========================= Raspberry Pi Vision UART Control ========================= */

static void Vision_UART_Start(void)
{
    HAL_NVIC_SetPriority(USART1_IRQn, 5, 0);
    HAL_NVIC_EnableIRQ(USART1_IRQn);

    vision_uart_line_len = 0;
    memset(vision_uart_line, 0, sizeof(vision_uart_line));

    HAL_UART_Receive_IT(&huart1, &vision_uart_rx_byte, 1);
}

static float Vision_Parse_Speed(const char *str, float default_speed, float max_speed)
{
    int value;

    if (str == NULL || *str == '\0')
    {
        return default_speed;
    }

    value = atoi(str);

    if (value <= 0)
    {
        return default_speed;
    }

    return limit_float((float)value, 0.0f, max_speed);
}

static void Vision_Mark_Valid_Gesture(void)
{
    uint32_t now;

    now = HAL_GetTick();

    vision_last_cmd_tick = now;
    vision_last_gesture_tick = now;
    vision_mode_active = 1;
    current_control_source = CONTROL_SOURCE_VISION;
}

static uint8_t Vision_Gesture_Is_Recent(void)
{
    uint32_t now;

    now = HAL_GetTick();

    if (vision_last_gesture_tick == 0U)
    {
        return 0;
    }

    if ((now - vision_last_gesture_tick) <= VISION_GESTURE_HOLD_MS)
    {
        return 1;
    }

    return 0;
}

static uint8_t Vision_Command_Is_Timed_Out(void)
{
    uint32_t now;

    now = HAL_GetTick();

    if (vision_last_cmd_tick == 0U)
    {
        return 1;
    }

    if ((now - vision_last_cmd_tick) > VISION_COMMAND_TIMEOUT_MS)
    {
        return 1;
    }

    return 0;
}

static void Vision_Set_Stop_All(void)
{
    vision_left_rpm = 0.0f;
    vision_right_rpm = 0.0f;

    vision_disc_enabled = 0;
    vision_right_target_pos = RIGHT_POS_0_RAD;

    /*
     * Do not force current_control_source to vision here.
     * Python may send STOP_ALL when it sees NO_HAND. If STOP_ALL forced vision mode,
     * the remote controller could never take back control while the camera sees no hand.
     */
    vision_last_cmd_tick = HAL_GetTick();
}

static void Vision_Set_Drive(float left_rpm, float right_rpm)
{
    vision_left_rpm = limit_float(left_rpm, -MAX_FORWARD_RPM, MAX_FORWARD_RPM);
    vision_right_rpm = limit_float(right_rpm, -MAX_FORWARD_RPM, MAX_FORWARD_RPM);

    Vision_Mark_Valid_Gesture();
}
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
int main(void)
{
  /* MCU Configuration--------------------------------------------------------*/

  /* Reset of all peripherals, Initializes the Flash interface and the Systick. */
  HAL_Init();

  /* Configure the system clock */
  SystemClock_Config();

  /* Initialize all configured peripherals */
  MX_GPIO_Init();
  MX_DMA_Init();
  MX_CAN1_Init();
  MX_CAN2_Init();
  MX_USART1_UART_Init();
  MX_USART3_UART_Init();
  MX_USART6_UART_Init();
  /* USER CODE BEGIN 2 */

  can_filter_init();

  /*
   * Reconfigure CAN2 reception to FIFO1 for DM4340 feedback logging.
   * CAN1 chassis feedback remains handled by the original RoboMaster CAN code.
   */
  DM_CAN2_Feedback_Filter_Init();
  DM_CAN2_Start_If_Needed();
  DM_CAN2_Feedback_Start();

  i6x_remote_init();

  Vision_UART_Start();

  current_control_source = CONTROL_SOURCE_REMOTE;
  vision_mode_active = 0;
  rc_last_active_tick = HAL_GetTick();

  chassis_stop();

  ZDT57_Stop();
  ZDT42_Stop();

  HAL_Delay(1000);

  DM_Init_Collecting_Disc(DM_LEFT_UP_ID);
  DM_Init_Collecting_Disc(DM_LEFT_DOWN_ID);
  DM_Init_Right_Rotate_Motor(DM_RIGHT_ROTATE_ID);

  DM_Stop_All();
  ZDT57_Stop();
  ZDT42_Stop();

  /* USER CODE END 2 */

  /* Infinite loop */
  /* USER CODE BEGIN WHILE */
  while (1)
  {
    /* USER CODE END WHILE */

    /* USER CODE BEGIN 3 */
    Control_Source_Update();

    if (current_control_source == CONTROL_SOURCE_VISION)
    {
        chassis_vision_control();
        DM_Vision_Control();
    }
    else
    {
        chassis_remote_control();
        DM_Remote_Control();
    }

    /*
     * SwC controls ZDT57 lift motor:
     *   up     -> stop
     *   middle -> reverse
     *   down   -> forward
     *
     * This motor is still remote-controlled only.
     */
    ZDT57_Remote_Control();

    /*
     * SwD controls ZDT42 drill motor:
     *   up   -> stop
     *   down -> run
     *   VRB  -> speed control
     *
     * The real drill is always remote-controlled only.
     * Raspberry Pi DRILL_ON/OFF does NOT control ZDT42 here.
     */
    ZDT42_Remote_Control();

    /*
     * Send DM4340 ID3 feedback to Raspberry Pi through USART6.
     */
    Telemetry_Send_DM3();

    HAL_Delay(CHASSIS_CONTROL_PERIOD_MS);
  }
  /* USER CODE END 3 */
}

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


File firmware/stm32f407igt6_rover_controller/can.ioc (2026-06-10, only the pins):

Mcu.UserName=STM32F407IGHx
PA13.Signal=SYS_JTMS-SWDIO
PA14.Signal=SYS_JTCK-SWCLK
PA9.Signal=USART1_TX
PB5.Signal=CAN2_RX
PB6.Signal=CAN2_TX
PB7.Signal=USART1_RX
PC10.Signal=USART3_TX
PC11.Signal=USART3_RX
PD0.Signal=CAN1_RX
PD1.Signal=CAN1_TX
PG14.Signal=USART6_TX
PG9.Signal=USART6_RX
PH0-OSC_IN.Signal=RCC_OSC_IN
PH1-OSC_OUT.Signal=RCC_OSC_OUT

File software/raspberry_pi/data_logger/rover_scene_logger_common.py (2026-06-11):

#!/usr/bin/env python3
# -*- coding: utf-8 -*-
"""
Integrated rover experiment logger for STM32 USART6 LOG output.

Place this file in:
    /home/pi/Desktop/rover_experiment/rover_scene_logger_common.py

Data are saved in:
    /home/pi/rover_logs/<scene_name>/

Important:
    This version does NOT rely on newline characters from the STM32.
    It can correctly split glued serial data like:
        LOG,...,0LOG,...,0LOG,...
"""
import argparse
import csv
import re
import time
from datetime import datetime
from pathlib import Path

import serial
import pandas as pd
import matplotlib
matplotlib.use("Agg")
import matplotlib.pyplot as plt

DEFAULT_PORT = "/dev/serial/by-path/platform-xhci-hcd.0-usb-0:2:1.0-port0"
DEFAULT_BAUD = 115200

COLUMNS = [
    "tag", "time_ms", "control_source",
    "lf_t", "lf_r", "rf_t", "rf_r", "lr_t", "lr_r", "rr_t", "rr_r",
    "dm3_online", "dm3_err", "dm3_rx_count", "dm3_pos_deg_x100", "dm3_vel_mrad_s",
    "dm3_torque_x100", "dm3_tmos", "dm3_trotor", "dm3_target_deg_x100", "stick_x",
    "zdt42_cmd_x10", "disc_cmd", "remote_ch0", "remote_ch1", "remote_ch3",
]

SCENE_CONFIG = {
    "flat_sand_demo": {
        "title": "Flat sand mobility and soil collection demonstration",
        "desc": "Forward/backward/turning, drill loosening, and collecting disc operation on flat sand.",
    },
    "slope_sand_demo": {
        "title": "Slope sand traversal demonstration",
        "desc": "Slope ascent/descent with arm posture and collecting disc assistance.",
    },
    "pit_escape_demo": {
        "title": "Pit escape demonstration",
        "desc": "Self-rescue using arm motion, drill/working mechanism, and wheel recovery.",
    },
}


class LogPacketExtractor:
    """
    Robust LOG packet extractor.

    The STM32 should ideally output one record per line:
        LOG,...\\r\\n

    But in real serial reading, records may be glued together:
        LOG,...,0LOG,...,0LOG,...

    This extractor uses the 'LOG,' marker itself as the packet boundary.
    """

    def __init__(self, expected_fields: int):
        self.expected_fields = expected_fields
        self.buffer = ""

    def feed(self, chunk: str):
        records = []

        if not chunk:
            return records

        # Normalize and remove control characters that may appear in serial streams.
        chunk = chunk.replace("\r", "").replace("\n", "")
        chunk = chunk.replace("\x00", "")

        self.buffer += chunk

        # Drop any leading garbage before the first LOG marker.
        first = self.buffer.find("LOG,")
        if first < 0:
            # Keep only a small tail in case "LOG," is split across chunks.
            self.buffer = self.buffer[-8:]
            return records
        if first > 0:
            self.buffer = self.buffer[first:]

        # Split before every LOG marker.
        parts = re.split(r"(?=LOG,)", self.buffer)

        # parts[0] may be empty. Keep the last segment in buffer because it may be incomplete.
        complete_parts = parts[:-1]
        self.buffer = parts[-1] if parts else ""

        for seg in complete_parts:
            rec = self.parse_segment(seg)
            if rec is not None:
                records.append(rec)

        return records

    def flush(self):
        rec = self.parse_segment(self.buffer)
        self.buffer = ""
        return [rec] if rec is not None else []

    def parse_segment(self, seg: str):
        seg = seg.strip()
        if not seg.startswith("LOG,"):
            return None

        parts = seg.split(",")

        # If a trailing glued record still leaked in, cut at the next LOG marker.
        # Usually this is already handled by split, but this keeps the parser safe.
        cleaned = []
        for p in parts:
            if "LOG" in p and p != "LOG":
                before, _, after = p.partition("LOG")
                if before:
                    cleaned.append(before)
                break
            cleaned.append(p)
        parts = cleaned

        if len(parts) < self.expected_fields:
            return None

        # Use exactly the expected number of fields. Extra bytes are ignored.
        parts = parts[:self.expected_fields]

        if parts[0] != "LOG":
            return None

        # Basic validation: time_ms should be numeric.
        try:
            int(float(parts[1]))
        except Exception:
            return None

        return parts


def ensure_dir(path: Path) -> None:
    path.mkdir(parents=True, exist_ok=True)


def load_and_process(csv_path: Path) -> pd.DataFrame:
    df = pd.read_csv(csv_path)
    if df.empty:
        raise RuntimeError("CSV is empty: no LOG rows were recorded.")

    for col in ["scene"] + COLUMNS:
        if col not in df.columns:
            raise RuntimeError(f"Missing column: {col}")

    for col in COLUMNS:
        if col != "tag":
            df[col] = pd.to_numeric(df[col], errors="coerce")

    df = df[df["tag"] == "LOG"].copy()
    df = df.dropna(subset=["time_ms"])

    if len(df) < 2:
        raise RuntimeError("Not enough valid LOG rows for plotting.")

    df["time_s"] = (df["time_ms"] - df["time_ms"].iloc[0]) / 1000.0
    df["left_target_rpm"] = (df["lf_t"] + df["lr_t"]) / 2.0
    df["left_actual_rpm"] = (df["lf_r"] + df["lr_r"]) / 2.0
    df["right_target_rpm"] = (df["rf_t"] + df["rr_t"]) / 2.0
    df["right_actual_rpm"] = (df["rf_r"] + df["rr_r"]) / 2.0
    df["avg_abs_wheel_rpm"] = (df[["lf_r", "rf_r", "lr_r", "rr_r"]].abs().sum(axis=1)) / 4.0

    df["dm3_pos_deg"] = df["dm3_pos_deg_x100"] / 100.0
    df["dm3_target_deg"] = df["dm3_target_deg_x100"] / 100.0
    df["dm3_vel_rad_s"] = df["dm3_vel_mrad_s"] / 1000.0
    df["dm3_torque"] = df["dm3_torque_x100"] / 100.0

    df["zdt42_cmd_rpm"] = df["zdt42_cmd_x10"] / 10.0
    return df


def save_plot(fig, out_dir: Path, stem: str):
    fig.tight_layout()
    fig.savefig(out_dir / f"{stem}.png", dpi=300)
    fig.savefig(out_dir / f"{stem}.pdf")
    plt.close(fig)
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

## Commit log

2026-06-11 Reorganize repository as full rover open-source project
    [Aluminum_Block_8_8_25.SLDPRT, Bucket_Arm_Stopper.SLDPRT, Bucket_Arm_Upright_Reinforcement_Clamp_Block.SLDPRT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]
2026-06-24 Add field-test logs and processed result figures
    [flat_sand_demo_log.csv, pit_escape_demo_log.csv, slope_sand_demo_log.csv]

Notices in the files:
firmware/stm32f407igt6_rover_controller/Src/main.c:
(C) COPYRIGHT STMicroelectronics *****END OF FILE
